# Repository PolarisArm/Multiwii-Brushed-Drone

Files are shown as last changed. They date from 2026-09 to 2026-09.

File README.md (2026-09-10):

# Multiwii-Brushed-Drone
Brushed Drone with Multiwii

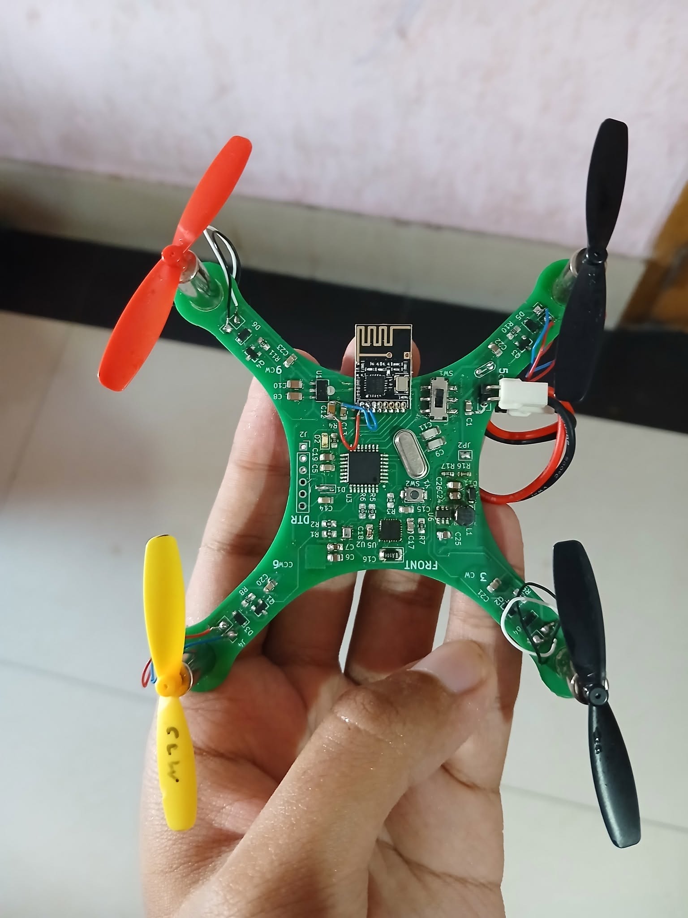
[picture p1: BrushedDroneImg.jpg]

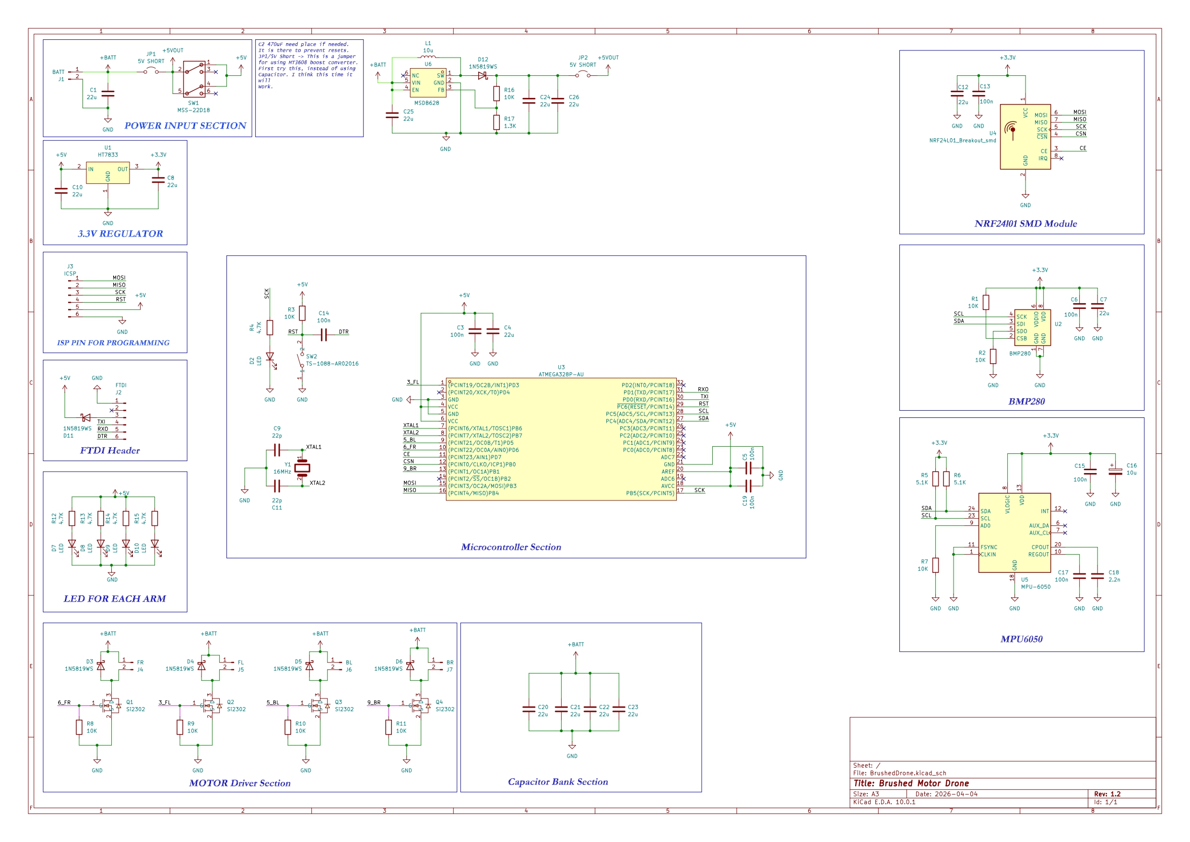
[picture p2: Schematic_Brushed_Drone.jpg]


# Orientation Code need to be changed as per MPU6050 Placement
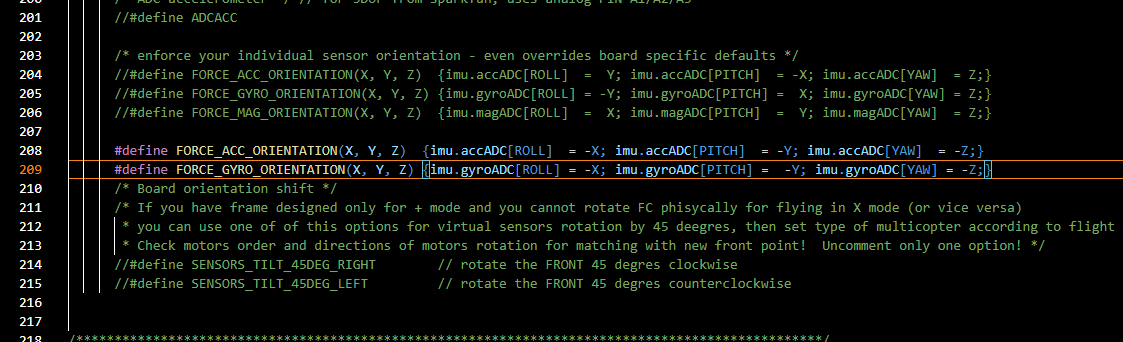
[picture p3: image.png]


# Vibration Issue mitigated by using low pass filter
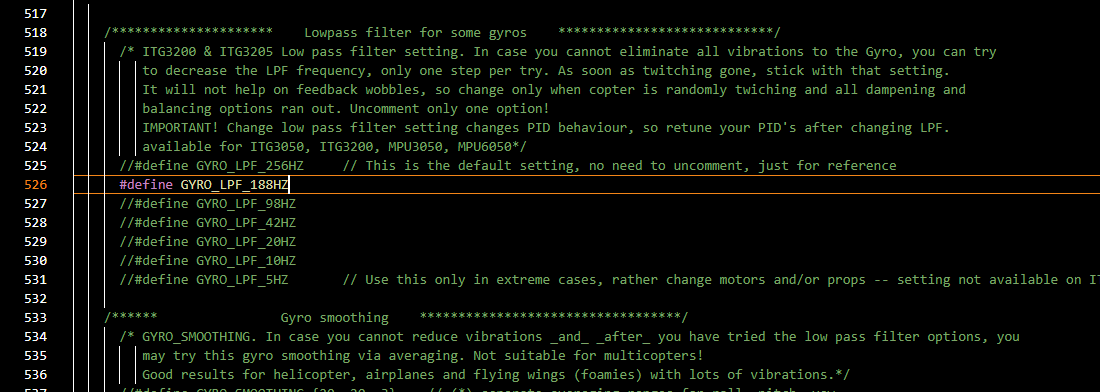
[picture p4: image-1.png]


# Dead band Added
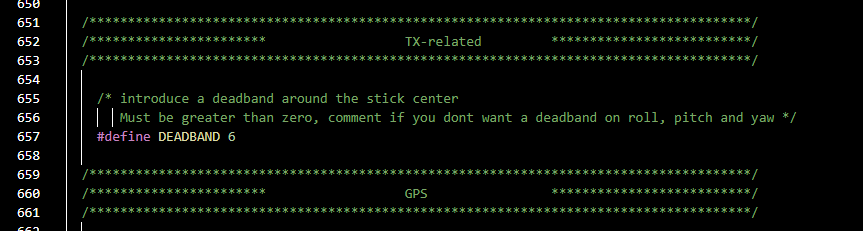
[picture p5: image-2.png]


# Multiwii 2.4 Software picture
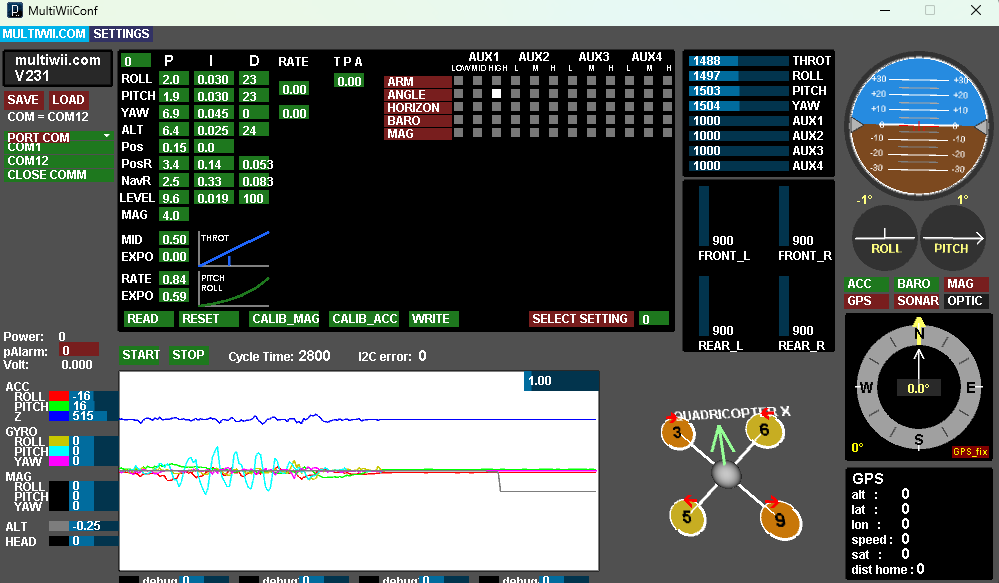
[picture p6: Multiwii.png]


#Transmitter Schematic
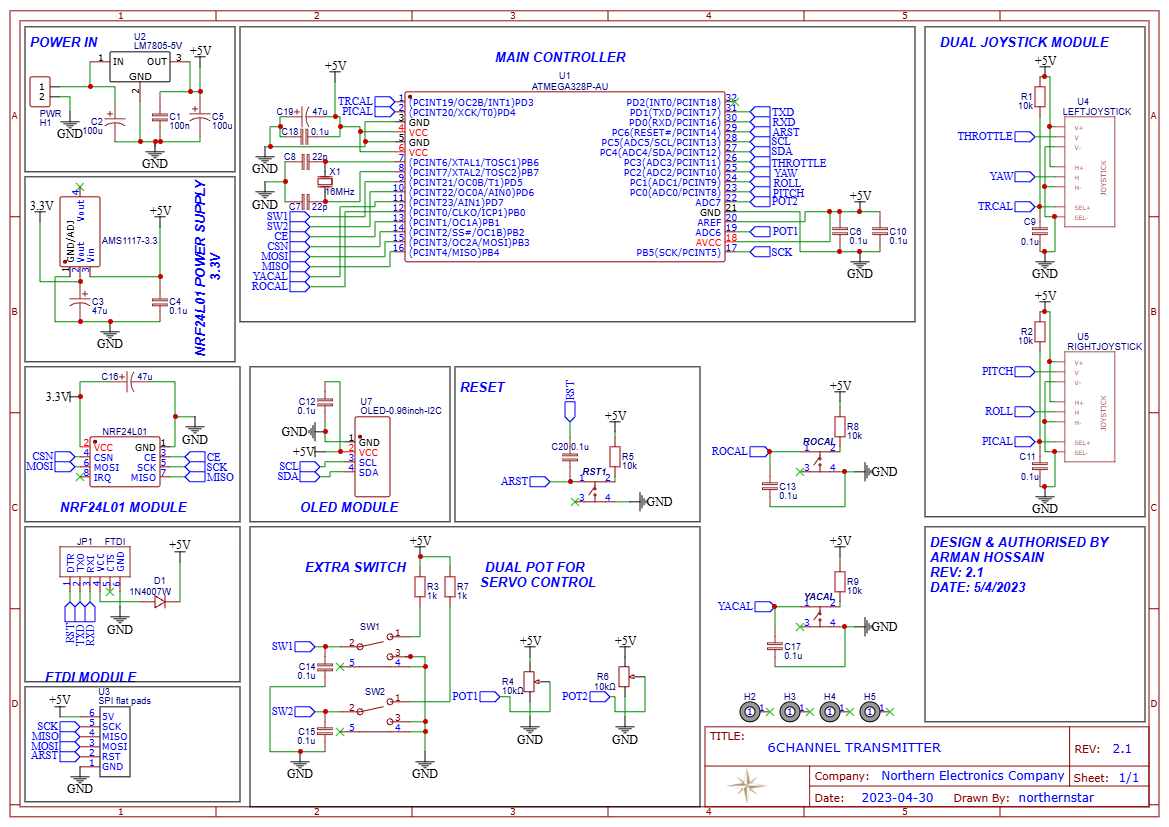
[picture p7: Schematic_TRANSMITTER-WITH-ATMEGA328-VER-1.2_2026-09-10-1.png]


# Transmitter
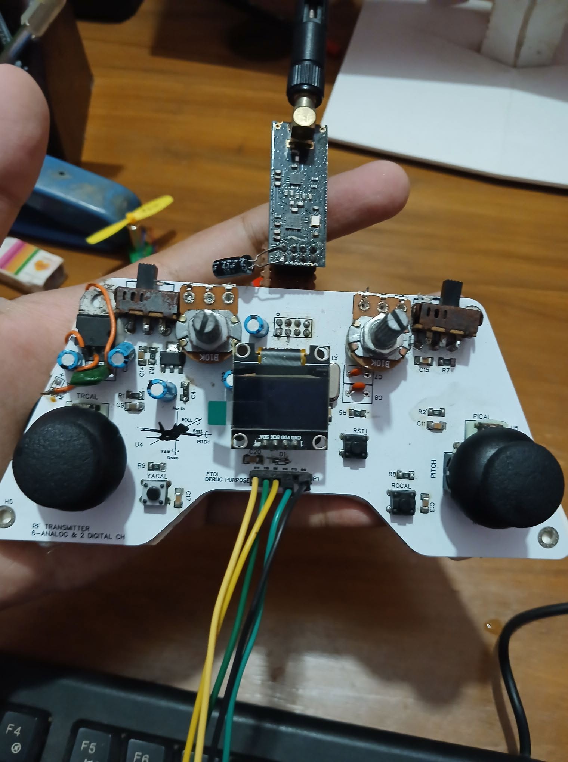
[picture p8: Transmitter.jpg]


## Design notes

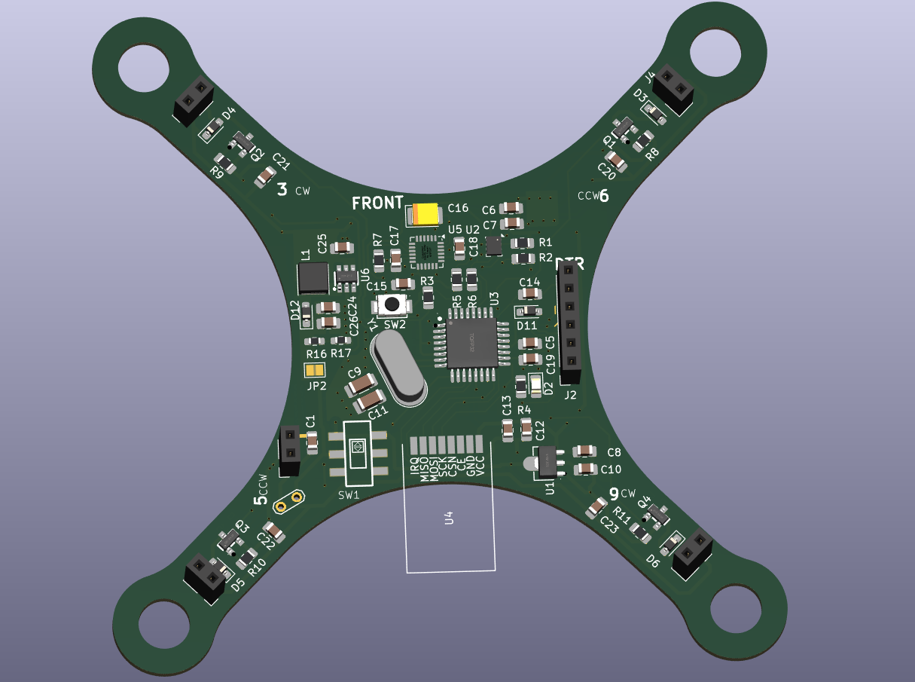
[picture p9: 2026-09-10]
PCB_3DView.png

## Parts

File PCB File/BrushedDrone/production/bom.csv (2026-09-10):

Designator | Footprint | Quantity | Value | LCSC Part #
C1, C10, C12, C20, C21, C22, C23, C24, C25, C26, C4, C7, C8 | 0805 | 13 | 22u
C11, C9 | 1206 | 2 | 22p
C13, C14, C15, C17, C19, C3, C5, C6 | 0805 | 8 | 100n
C16 | CP_EIA-3528-12_Kemet-T_HandSolder | 1 | 10u
C18 | 0805 | 1 | 2.2n
D1, D3, D4, D5, D6 | D_SOD-323_HandSoldering | 5 | 1N5819WS
D10, D2, D7, D8, D9 | 0805 | 5 | LED
D11 | D_SOD-323 | 1 | 1N5819WS
J1 | PinSocket_1x02_P2.54mm_Vertical | 1 | BATT
J2 | PinSocket_1x06_P2.54mm_Vertical | 1 | FTDI
J3 | ICSP_PAD | 1 | ICSP
J4 | PinSocket_1x02_P2.54mm_Vertical | 1 | FR
J5 | PinSocket_1x02_P2.54mm_Vertical | 1 | FL
J6 | PinSocket_1x02_P2.54mm_Vertical | 1 | BL
J7 | PinSocket_1x02_P2.54mm_Vertical | 1 | BR
JP1 | TestPoint_2Pads_Pitch2.54mm_Drill0.8mm | 1 | 5V SHORT
JP2 | SolderJumper-2_P1.3mm_Open_Pad1.0x1.5mm | 1 | 5V SHORT
L1 | L_APV_ANR4020 | 1 | 10u
Q1, Q2, Q3, Q4 | SOT-23_L2.9-W1.3-P1.90-LS2.4-BR | 4 | Si2302 | C10488
R1, R10, R11, R2, R3, R7, R8, R9 | 0805 | 8 | 10K
R12, R13, R14, R15, R4 | 0805 | 5 | 4.7K
R16 | 0603 | 1 | 10K
R17 | 0603 | 1 | 1.3K
R5, R6 | 0805 | 2 | 5.1K
SW1 | MSS2D18 | 1 | MSS-22D18
SW2 | SW-SMD_L3.9-W3.0-P4.45 | 1 | TS-1088-AR02016 | C720477
U1 | SOT-89_L4.5-W2.5-P1.50-LS4.2-BR | 1 | HT7833 | C50936
U2 | Bosch_LGA-8_2x2.5mm_P0.65mm_ClockwisePinNumbering | 1 | BMP280
U3 | TQFP-32_L7.0-W7.0-P0.80-LS9.0-BL | 1 | ATMEGA328P-AU | C14877
U4 | FootprintsKeyplus_nordic.prettyNRF24L01-Module-SMD | 1 | NRF24L01_Breakout_smd
U5 | InvenSense_QFN-24_4x4mm_P0.5mm | 1 | MPU-6050
U6 | SOT-23-6_L2.9-W1.6-P0.95-LS2.8-BR | 1 | MSDB628 | C30197563
Y1 | Crystal_HC49-4H_Vertical | 1 | 16MHz

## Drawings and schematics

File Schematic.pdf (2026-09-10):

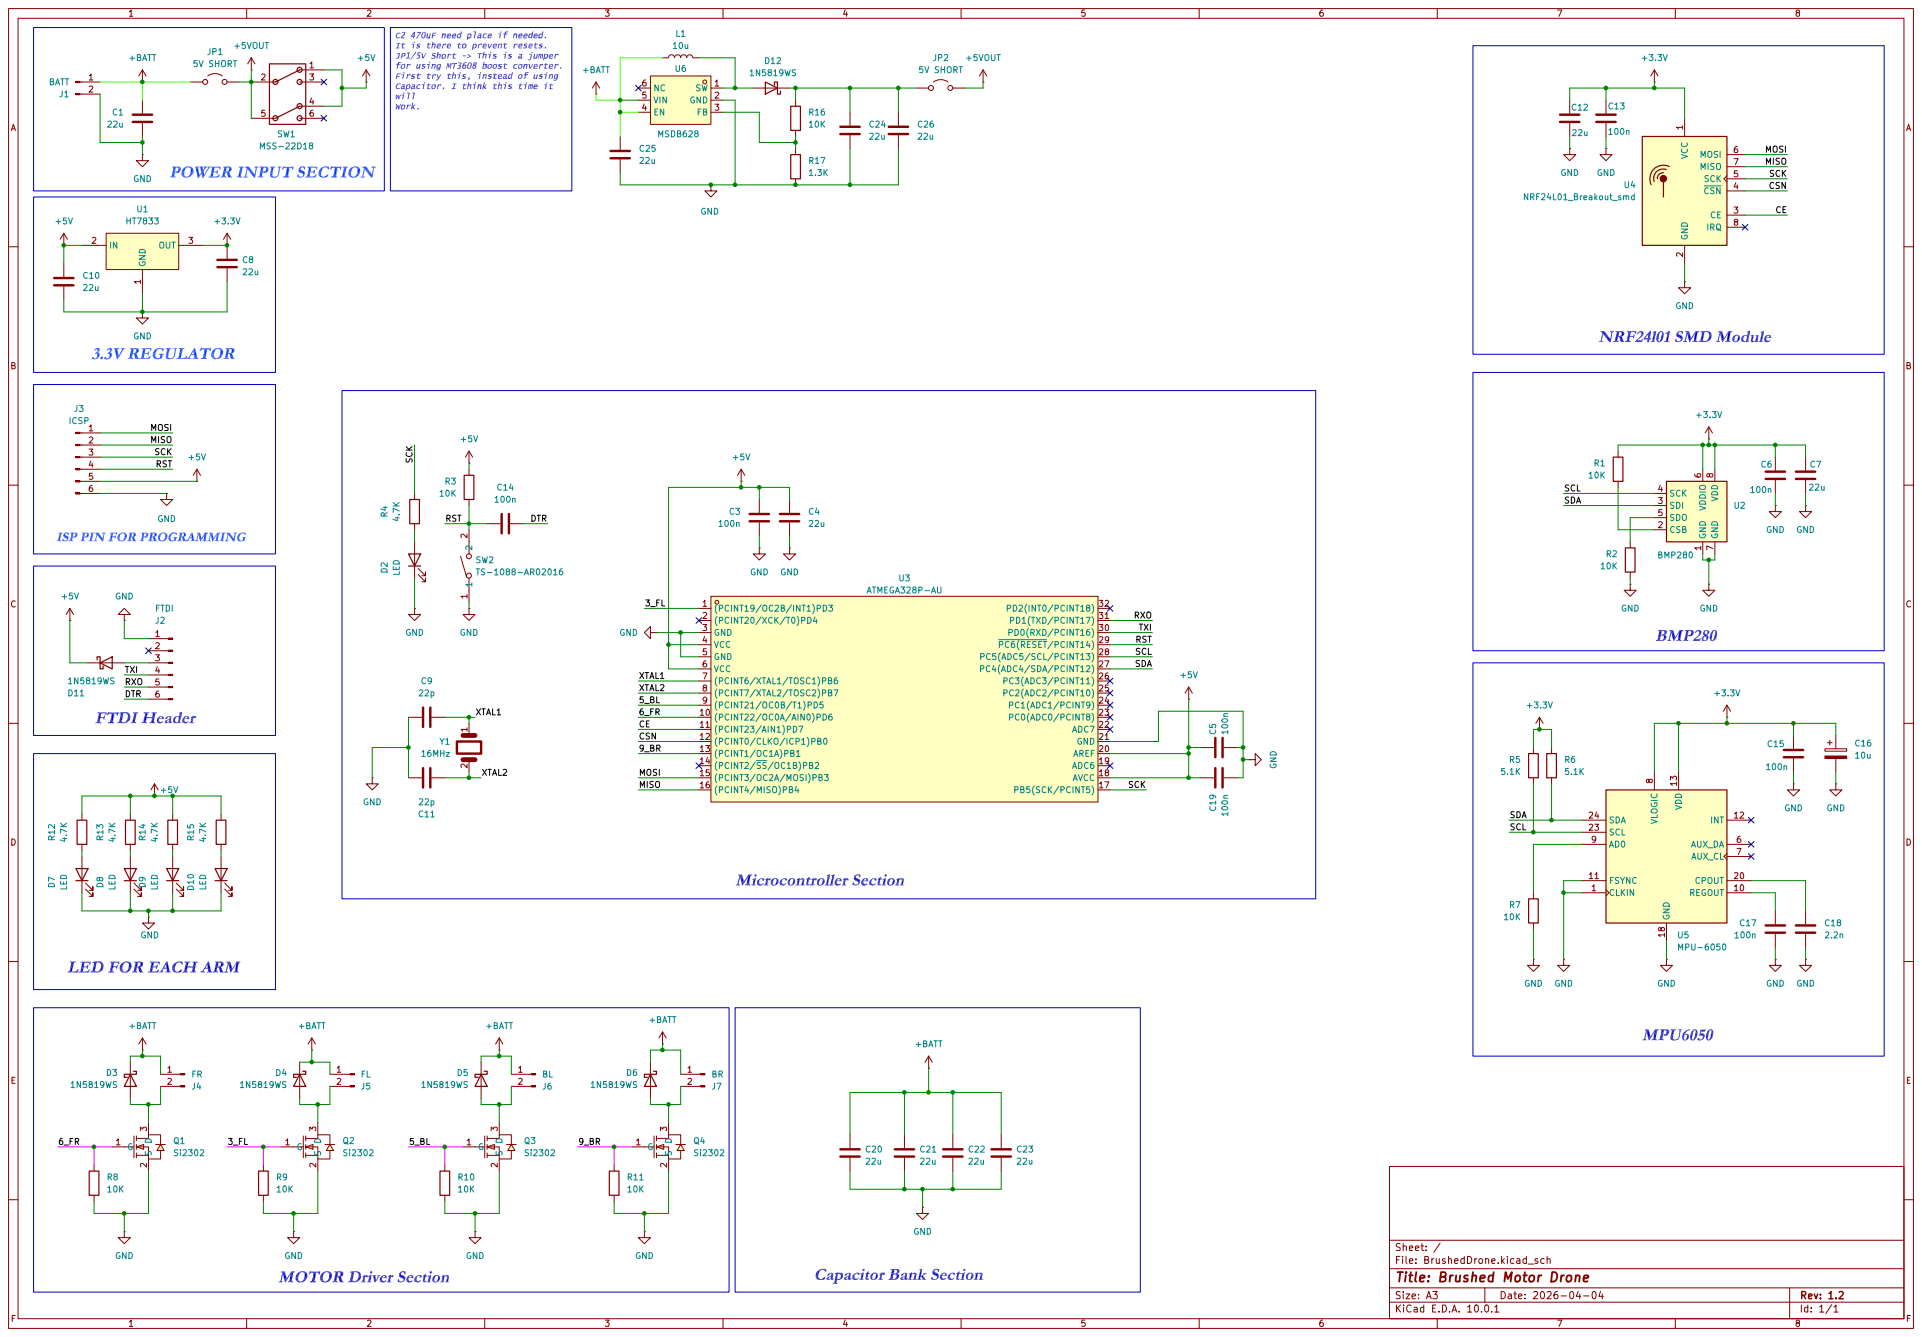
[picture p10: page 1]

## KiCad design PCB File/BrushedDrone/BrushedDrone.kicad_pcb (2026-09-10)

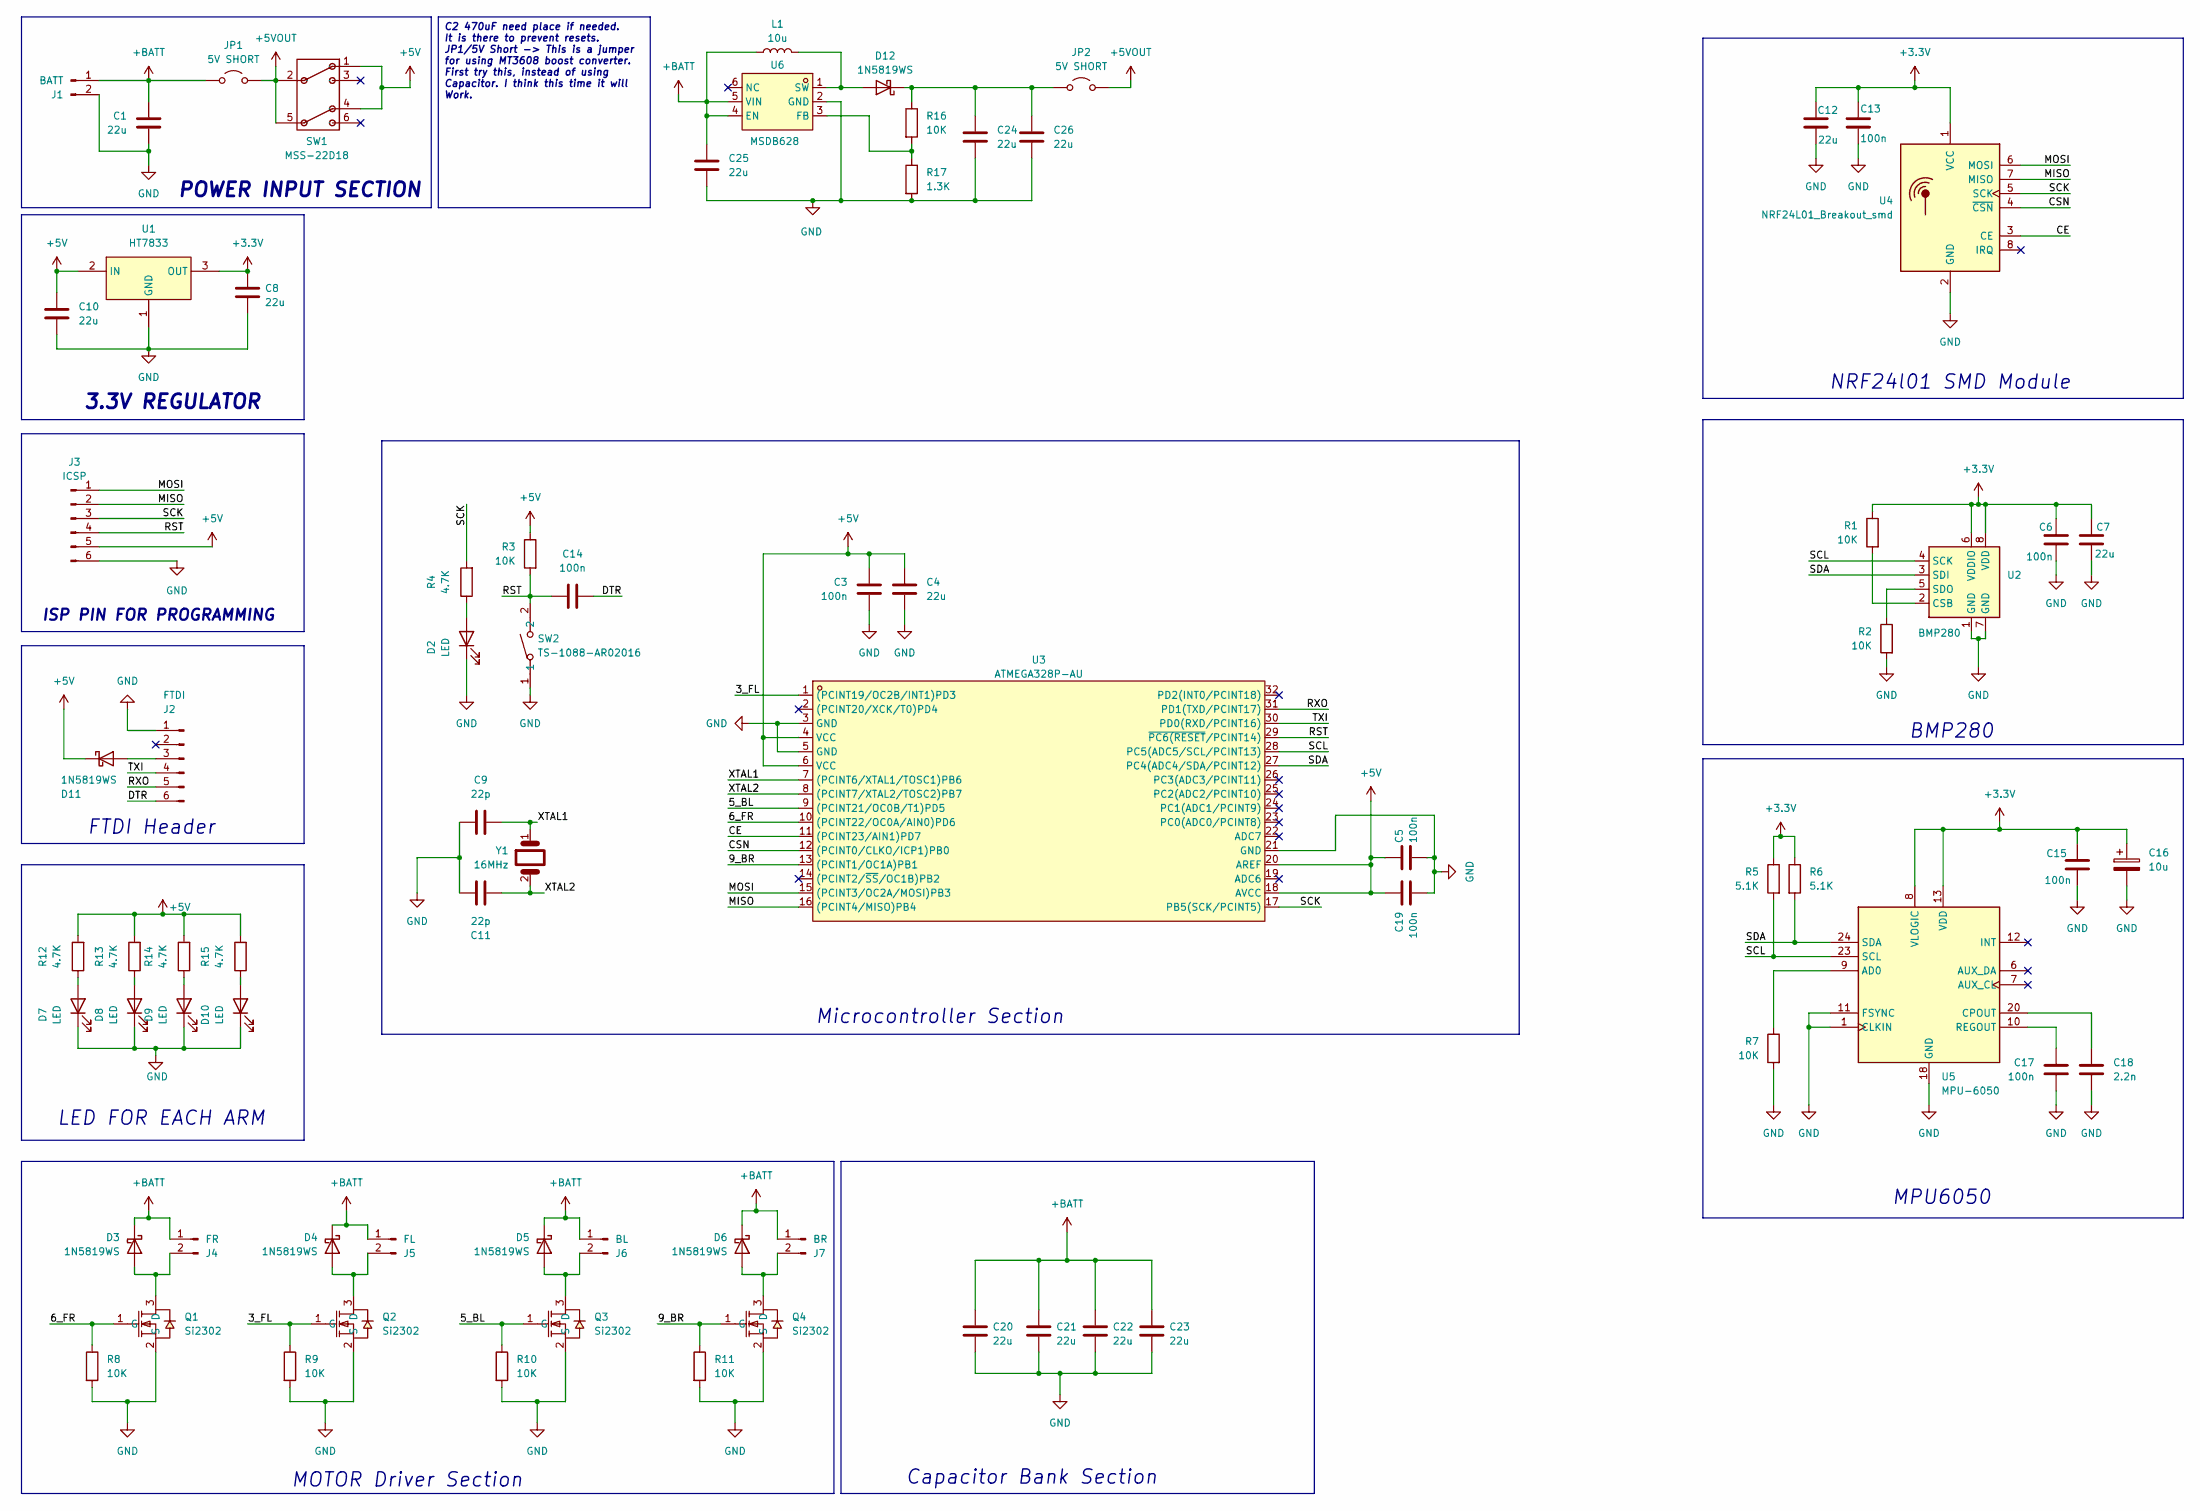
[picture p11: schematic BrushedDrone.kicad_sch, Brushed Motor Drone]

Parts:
C1, C4, C7, C8, C10, C12, C20, C21, C22, C23, C24, C25, C26: 22u; C_0805_2012Metric_Pad1.18x1.45mm_HandSolder
C3, C5, C6, C13, C14, C15, C17, C19: 100n; C_0805_2012Metric_Pad1.18x1.45mm_HandSolder
C9, C11: 22p; C_1206_3216Metric_Pad1.33x1.80mm_HandSolder
C16: 10u; CP_EIA-3528-12_Kemet-T_HandSolder
C18: 2.2n; C_0805_2012Metric_Pad1.18x1.45mm_HandSolder
D2, D7, D8, D9, D10: LED; LED_0805_2012Metric_Pad1.15x1.40mm_HandSolder
D3, D4, D5, D6, D11, D12: 1N5819WS; D_SOD-323_HandSoldering
J1: BATT; PinSocket_1x02_P2.54mm_Vertical
J2: FTDI; PinSocket_1x06_P2.54mm_Vertical
J3: ICSP; ICSP_PAD
J4: FR; PinSocket_1x02_P2.54mm_Vertical
J5: FL; PinSocket_1x02_P2.54mm_Vertical
J6: BL; PinSocket_1x02_P2.54mm_Vertical
J7: BR; PinSocket_1x02_P2.54mm_Vertical
JP1: 5V SHORT; TestPoint_2Pads_Pitch2.54mm_Drill0.8mm
JP2: 5V SHORT; SolderJumper-2_P1.3mm_Open_Pad1.0x1.5mm
L1: 10u; L_APV_ANR4020
Q1, Q2, Q3, Q4: Si2302; SOT-23_L2.9-W1.3-P1.90-LS2.4-BR; MPN Si2302CDS-T1-GE3; LCSC Part C10488
R1, R2, R3, R7, R8, R9, R10, R11: 10K; R_0805_2012Metric_Pad1.20x1.40mm_HandSolder
R4, R12, R13, R14, R15: 4.7K; R_0805_2012Metric_Pad1.20x1.40mm_HandSolder
R5, R6: 5.1K; R_0805_2012Metric_Pad1.20x1.40mm_HandSolder
R16: 10K; R_0603_1608Metric_Pad0.98x0.95mm_HandSolder
R17: 1.3K; R_0603_1608Metric_Pad0.98x0.95mm_HandSolder
SW1: MSS-22D18; MSS2D18
SW2: TS-1088-AR02016; SW-SMD_L3.9-W3.0-P4.45; MPN TS-1088-AR02016; LCSC Part C720477
U1: HT7833; SOT-89_L4.5-W2.5-P1.50-LS4.2-BR; MPN HT7833; LCSC Part C50936
U2: BMP280; Bosch_LGA-8_2x2.5mm_P0.65mm_ClockwisePinNumbering
U3: ATMEGA328P-AU; TQFP-32_L7.0-W7.0-P0.80-LS9.0-BL; MPN ATMEGA328P-AU; LCSC Part C14877
U4: NRF24L01_Breakout_smd; FootprintsKeyplus_nordic.prettyNRF24L01-Module-SMD
U5: MPU-6050; InvenSense_QFN-24_4x4mm_P0.5mm
U6: MSDB628; SOT-23-6_L2.9-W1.6-P0.95-LS2.8-BR; MPN MSDB628; LCSC Part C30197563
Y1: 16MHz; Crystal_HC49-4H_Vertical

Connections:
+3.3V: C6.1, C7.1, C8.1, C12.1, C13.1, C15.1, C16.1, R1.1, R5.1, R6.1, U1.3 (OUT), U2.6 (VDDIO), U2.8 (VDD), U4.1 (VCC), U5.8 (VLOGIC), U5.13 (VDD)
+5V: C3.1, C4.1, C5.1, C10.1, C19.1, D11.1 (K), J3.5, R3.1, R12.2, R13.2, R14.2, R15.2, SW1.1, SW1.4, U1.2 (IN), U3.4 (VCC), U3.6 (VCC), U3.18 (AVCC), U3.20 (AREF)
+5VOUT: JP1.2 (B), JP2.2 (B), SW1.2, SW1.5
+BATT: C1.1, C20.1, C21.1, C22.1, C23.1, C25.1, D3.1 (K), D4.1 (K), D5.1 (K), D6.1 (K), J1.1, J4.1, J5.1, J6.1, J7.1, JP1.1 (A), L1.1, U6.4 (EN), U6.5 (VIN)
/3_FL: Q2.1 (G), R9.1, U3.1 ((PCINT19/OC2B/INT1)PD3)
/5_BL: Q3.1 (G), R10.1, U3.9 ((PCINT21/OC0B/T1)PD5)
/6_FR: Q1.1 (G), R8.1, U3.10 ((PCINT22/OC0A/AIN0)PD6)
/9_BR: Q4.1 (G), R11.1, U3.13 ((PCINT1/OC1A)PB1)
/CE: U3.11 ((PCINT23/AIN1)PD7), U4.3 (CE)
/CSN: U3.12 ((PCINT0/CLKO/ICP1)PB0), U4.4 (~CSN)
/DTR: C14.2, J2.6
/MISO: J3.2, U3.16 ((PCINT4/MISO)PB4), U4.7 (MISO)
/MOSI: J3.1, U3.15 ((PCINT3/OC2A/MOSI)PB3), U4.6 (MOSI)
/RST: C14.1, J3.4, R3.2, SW2.2, U3.29 (~PC6(RESET/PCINT14))
/RXO: J2.5, U3.31 (PD1(TXD/PCINT17))
/SCK: J3.3, R4.2, U3.17 (PB5(SCK/PCINT5)), U4.5 (SCK)
/SCL: R5.2, U2.4 (SCK), U3.28 (PC5(ADC5/SCL/PCINT13)), U5.23 (SCL)
/SDA: R6.2, U2.3 (SDI), U3.27 (PC4(ADC4/SDA/PCINT12)), U5.24 (SDA)
/TXI: J2.4, U3.30 (PD0(RXD/PCINT16))
/XTAL1: C9.1, U3.7 ((PCINT6/XTAL1/TOSC1)PB6), Y1.1
/XTAL2: C11.1, U3.8 ((PCINT7/XTAL2/TOSC2)PB7), Y1.2
GND: C1.2, C3.2, C4.2, C5.2, C6.2, C7.2, C8.2, C9.2, C10.2, C11.2, C12.2, C13.2, C15.2, C16.2, C17.2, C18.2, C19.2, C20.2, C21.2, C22.2, C23.2, C24.2, C25.2, C26.2, D2.1 (K), D7.1 (K), D8.1 (K), D9.1 (K), D10.1 (K), J1.2, J2.1, J3.6, Q1.2 (S), Q2.2 (S), Q3.2 (S), Q4.2 (S), R2.2, R7.2, R8.2, R9.2, R10.2, R11.2, R17.2, SW2.1, U1.1 (GND), U2.1 (GND), U2.7 (GND), U3.3 (GND), U3.5 (GND), U3.21 (GND), U4.2 (GND), U5.1 (CLKIN), U5.11 (FSYNC), U5.18 (GND), U6.2 (GND)
unnamed: D2.2 (A), R4.1
unnamed: D3.2 (A), J4.2, Q1.3 (D)
unnamed: D4.2 (A), J5.2, Q2.3 (D)
unnamed: D5.2 (A), J6.2, Q3.3 (D)
unnamed: D6.2 (A), J7.2, Q4.3 (D)
unnamed: D7.2 (A), R12.1
unnamed: D8.2 (A), R13.1
unnamed: D9.2 (A), R14.1
unnamed: D10.2 (A), R15.1
unnamed: D11.2 (A), J2.3
unnamed: D12.2 (A), L1.2, U6.1 (SW)
unnamed: C24.1, C26.1, D12.1 (K), JP2.1 (A), R16.1
unnamed: R1.2, U2.2 (CSB)
unnamed: R2.1, U2.5 (SDO)
unnamed: R7.1, U5.9 (AD0)
unnamed: C18.1, U5.20 (CPOUT)
unnamed: C17.1, U5.10 (REGOUT)
unnamed: R16.2, R17.1, U6.3 (FB)

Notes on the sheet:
NRF24l01 SMD Module
BMP280
ISP PIN FOR PROGRAMMING
MOTOR Driver Section
MPU6050
LED FOR EACH ARM
POWER INPUT SECTION
Microcontroller Section
3.3V REGULATOR
Capacitor Bank Section
FTDI Header
C2 470uF need place if needed. It is there to prevent resets. JP1/5V Short -> This is a jumper for using MT3608 boost converter. First try this, instead of using Capacitor. I think this time it will Work.

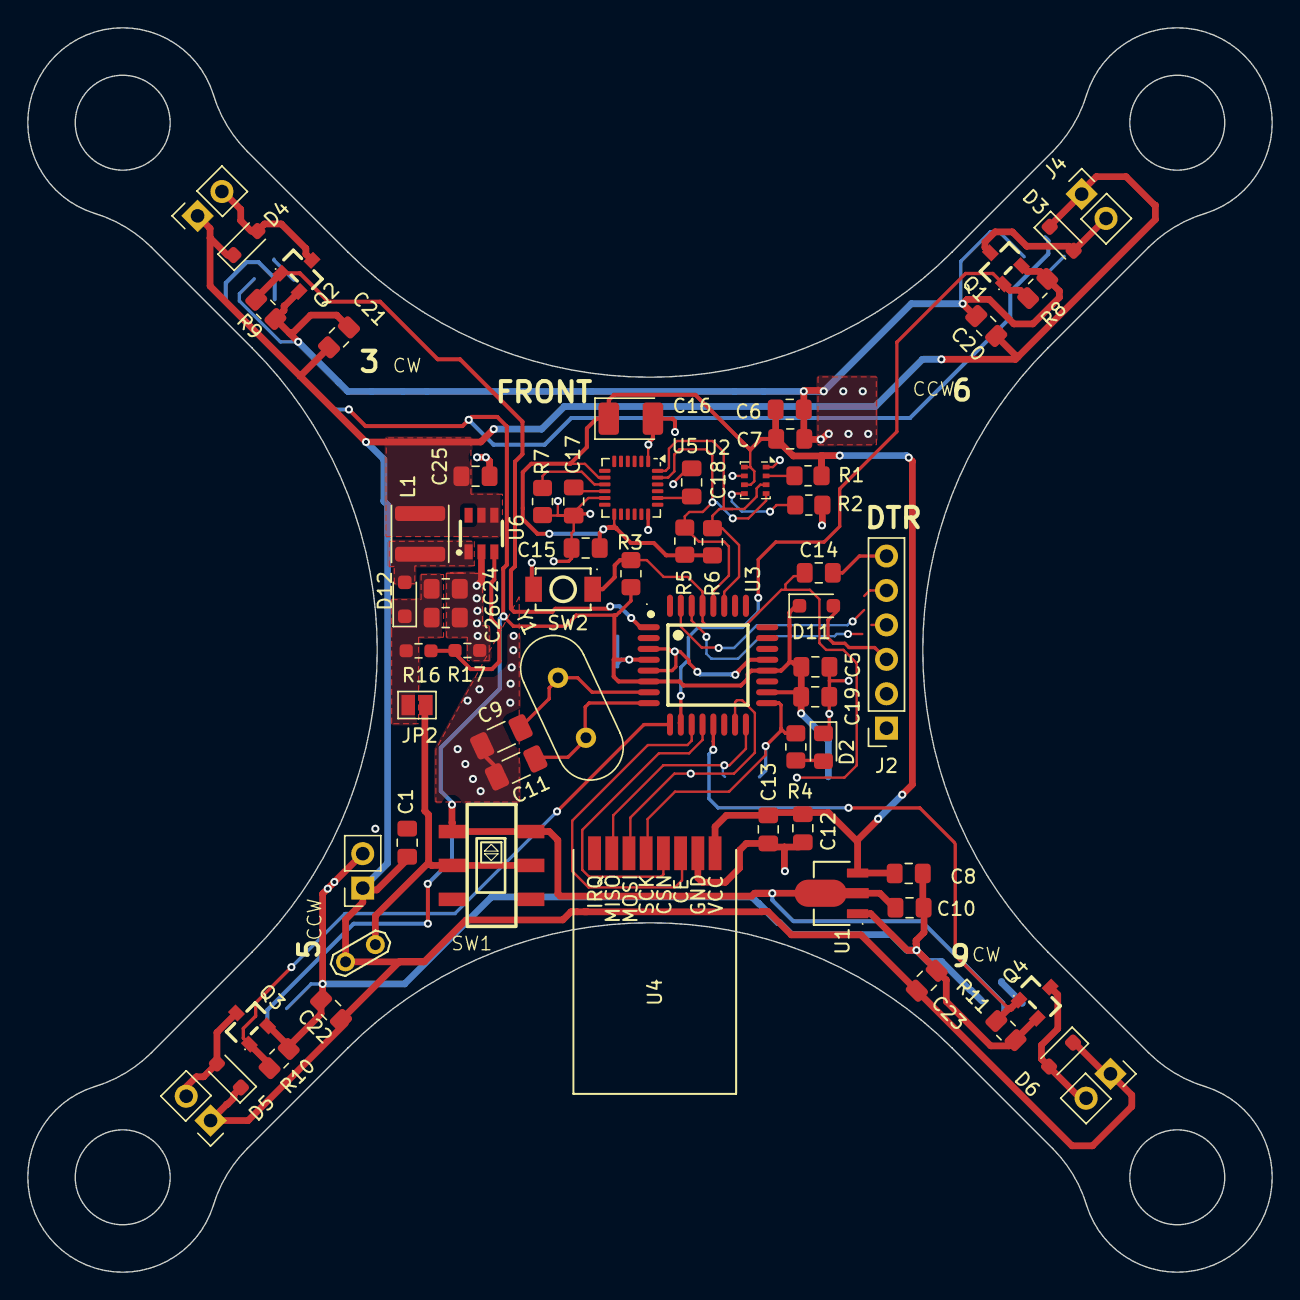
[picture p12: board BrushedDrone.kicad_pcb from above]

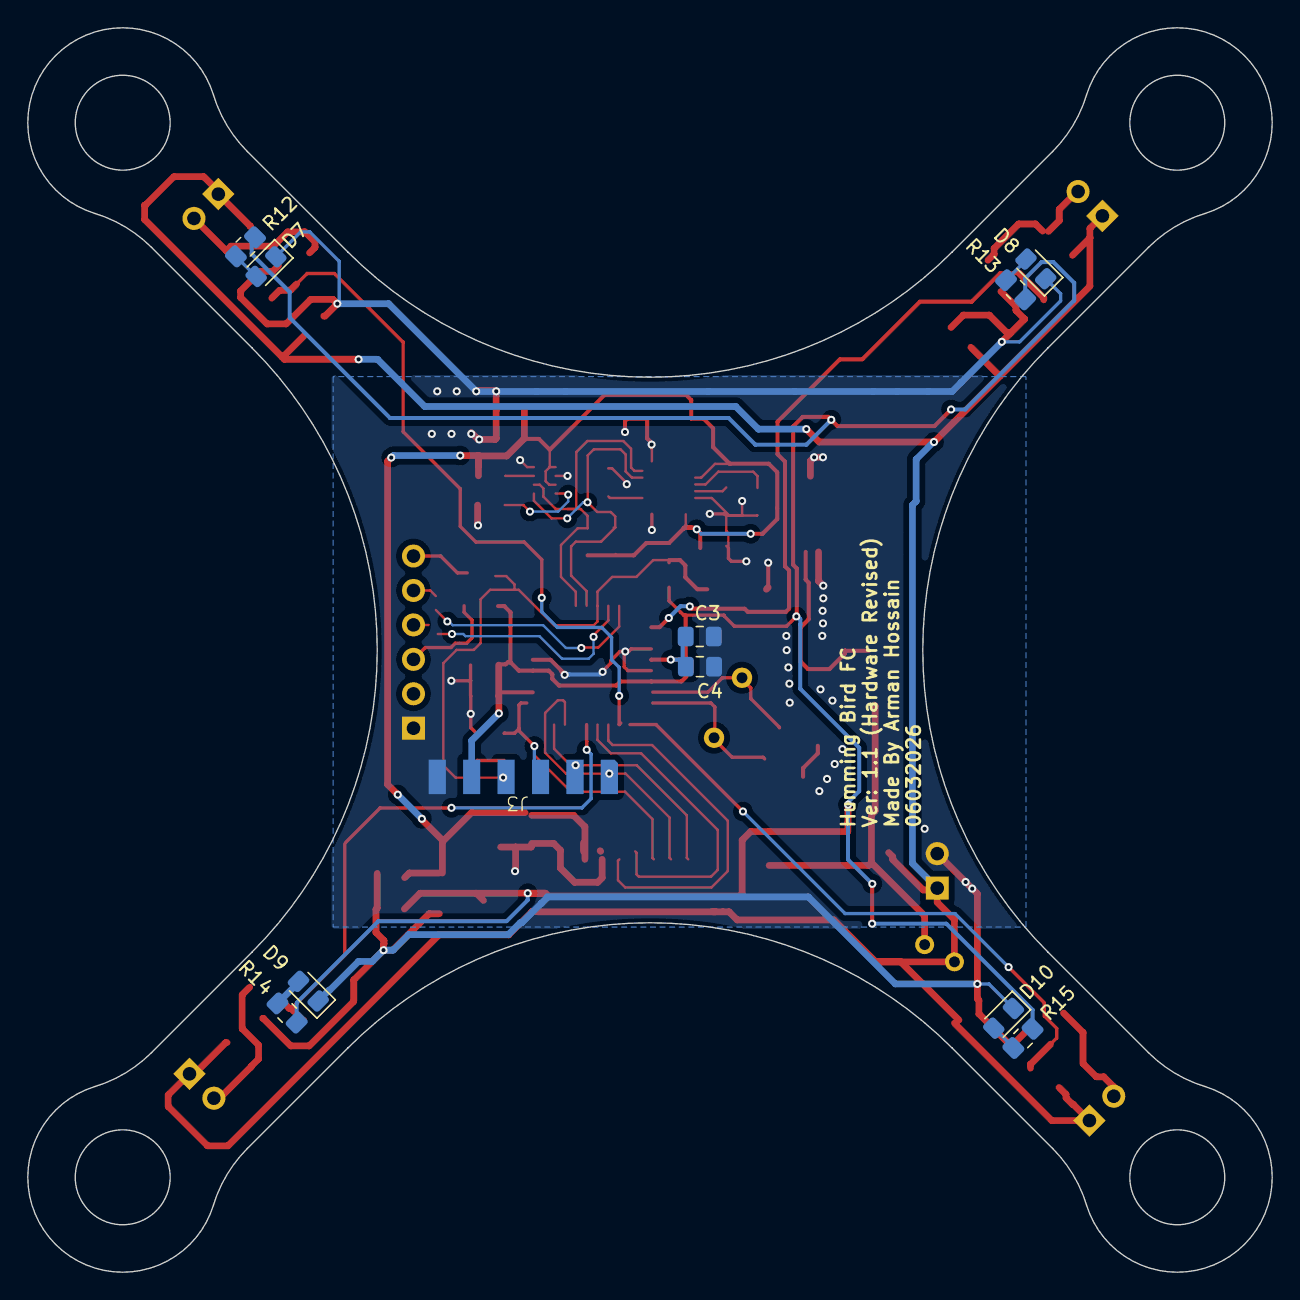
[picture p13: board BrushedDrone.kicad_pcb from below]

Board: 2 copper layers, 91.8 x 91.8 mm, 76 parts (11 on the bottom side), 40 nets.

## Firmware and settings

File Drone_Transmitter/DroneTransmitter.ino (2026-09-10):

#include <Arduino.h>
#include <Adafruit_GFX.h>
#include <Adafruit_SSD1306.h>
#include <RF24.h>

#define CE         9
#define CSN       10
#define ROLL      A1
#define PITCH     A0
#define YAW       A2
#define THROTTLE  A3
#define SW1        5
#define SW2        6
#define POT1      A6
#define POT2      A7
#define TRCAL      3
#define YACAL      7
#define PICAL      4
#define ROCAL      8


#define SCREEN_WIDTH 128 // OLED display width, in pixels
#define SCREEN_HEIGHT 64 // OLED display height, in pixels

#define OLED_RESET     -1 // Reset pin # (or -1 if sharing Arduino reset pin)
#define SCREEN_ADDRESS 0x3C /// 0x3C for 128x64
Adafruit_SSD1306 display(SCREEN_WIDTH, SCREEN_HEIGHT);

int PITCH_CENTER = 0, ROLL_CENTER = 0, YAW_CENTER = 0, THROTTLE_CENTER = 0;

const unsigned char WELCOME_SCREEN [] PROGMEM = {
	0xff, 0xff, 0xff, 0xff, 0xff, 0xff, 0xff, 0xff, 0xff, 0xff, 0xff, 0xff, 0xff, 0xff, 0xff, 0xff, 
	0xff, 0xff, 0xff, 0xff, 0xff, 0xff, 0xff, 0xff, 0xff, 0xff, 0xff, 0xff, 0xff, 0xff, 0xff, 0xff, 
	0xff, 0xff, 0xff, 0xff, 0xff, 0xff, 0xff, 0xff, 0xff, 0xff, 0xff, 0xff, 0xff, 0xff, 0xff, 0xff, 
	0xff, 0xff, 0xff, 0xff, 0xff, 0xff, 0xff, 0xff, 0xff, 0xff, 0xff, 0xff, 0xff, 0xff, 0xff, 0xff, 
	0xff, 0xff, 0xff, 0xff, 0xff, 0xff, 0xff, 0xff, 0xff, 0xff, 0xff, 0xff, 0xff, 0xff, 0xff, 0xff, 
	0xff, 0xff, 0xff, 0xff, 0xff, 0xff, 0xff, 0xff, 0xff, 0xff, 0xff, 0xff, 0xff, 0xff, 0xff, 0xff, 
	0xff, 0xff, 0xff, 0xff, 0xff, 0xff, 0xff, 0xff, 0xff, 0xff, 0xff, 0xff, 0xff, 0xff, 0xff, 0xff, 
	0xc0, 0x07, 0xe0, 0x18, 0x1f, 0xf8, 0x0e, 0x00, 0x38, 0x1f, 0x00, 0x7f, 0xfc, 0x00, 0x7c, 0x01, 
	0xd0, 0x03, 0x40, 0x0a, 0x1f, 0xd0, 0x06, 0x80, 0x1a, 0x1a, 0x00, 0x7f, 0xfd, 0x00, 0x28, 0x03, 
	0xc0, 0xc3, 0x03, 0x08, 0x1f, 0xc0, 0xc2, 0x06, 0x18, 0x18, 0x00, 0xff, 0xfc, 0x0c, 0x20, 0x7f, 
	0xc0, 0xc3, 0x03, 0x08, 0x1f, 0xc0, 0xc2, 0x06, 0x18, 0x18, 0x1f, 0xff, 0xfc, 0x0c, 0x20, 0x7f, 
	0xc0, 0xc3, 0x03, 0x08, 0x1f, 0xc0, 0x02, 0x00, 0x38, 0x18, 0x00, 0xff, 0xfc, 0x00, 0x60, 0x7f, 
	0xc0, 0x03, 0x03, 0x08, 0x1f, 0xc0, 0xc2, 0x00, 0x78, 0x1c, 0x00, 0x7f, 0xfc, 0x00, 0xe0, 0x7f, 
	0xc0, 0x07, 0x03, 0x08, 0x1f, 0xc0, 0xc2, 0x00, 0x38, 0x1f, 0xf8, 0x7f, 0xfc, 0x00, 0x60, 0x7f, 
	0xc0, 0x0f, 0x03, 0x08, 0x1f, 0xc0, 0xc2, 0x00, 0x18, 0x1c, 0x00, 0x7f, 0xfc, 0x00, 0x20, 0x7f, 
	0xc0, 0xff, 0x00, 0x08, 0x01, 0xc0, 0xc2, 0x04, 0x18, 0x18, 0x00, 0x7f, 0xfc, 0x08, 0x20, 0x03, 
	0xc0, 0xff, 0x80, 0x18, 0x00, 0xc0, 0xc2, 0x06, 0x18, 0x18, 0x00, 0xff, 0xfc, 0x0c, 0x30, 0x01, 
	0xe1, 0xff, 0xc0, 0x3c, 0x01, 0xe1, 0xe7, 0x0f, 0x3c, 0x3c, 0x01, 0xff, 0xfe, 0x1e, 0x78, 0x03, 
	0xff, 0xff, 0xff, 0xff, 0xff, 0xff, 0xff, 0xff, 0xff, 0xff, 0xff, 0xff, 0xff, 0xff, 0xff, 0xff, 
	0xff, 0xff, 0xff, 0xff, 0xff, 0xff, 0xff, 0xff, 0xff, 0xff, 0xff, 0xff, 0xff, 0xff, 0xff, 0xff, 
	0xff, 0xff, 0xff, 0xff, 0xff, 0xff, 0xff, 0xff, 0xff, 0xff, 0xff, 0xff, 0xff, 0xff, 0xff, 0xff, 
	0xff, 0xff, 0xff, 0xff, 0xff, 0xff, 0xff, 0xff, 0xff, 0xff, 0xff, 0xff, 0xff, 0xff, 0xff, 0xff, 
	0xff, 0xff, 0xff, 0xff, 0xff, 0xc7, 0x8f, 0xff, 0xff, 0xff, 0xff, 0xff, 0xff, 0xff, 0xff, 0xff, 
	0xff, 0xff, 0x80, 0x20, 0x03, 0xb3, 0x07, 0xff, 0xff, 0xff, 0xff, 0x00, 0x78, 0x0f, 0x00, 0x1f, 
	0xff, 0xfd, 0x00, 0x28, 0x01, 0xa0, 0x07, 0xff, 0xff, 0xff, 0xfa, 0x00, 0xd0, 0x07, 0x40, 0x0f, 
	0xff, 0xfc, 0x00, 0x60, 0x61, 0xc0, 0x0f, 0xff, 0xff, 0xff, 0xf8, 0x1f, 0xc0, 0xc3, 0x03, 0x0f, 
	0xff, 0xfc, 0x0f, 0xe0, 0x61, 0xc0, 0x0f, 0xff, 0xff, 0xff, 0xf8, 0x1f, 0xc0, 0xc3, 0x03, 0x0f, 
	0xff, 0xfc, 0x00, 0x60, 0x61, 0xe0, 0x1f, 0xff, 0xff, 0xff, 0xf8, 0x1f, 0xc0, 0x03, 0x00, 0x1f, 
	0xff, 0xfe, 0x00, 0x20, 0x01, 0xf0, 0x7f, 0xff, 0xff, 0xff, 0xf8, 0x1f, 0xc0, 0xc3, 0x00, 0x3f, 
	0xff, 0xff, 0xfc, 0x20, 0x03, 0xf0, 0x7f, 0xff, 0xff, 0xff, 0xf8, 0x1f, 0xc0, 0xc3, 0x00, 0x1f, 
	0xff, 0xfe, 0x00, 0x20, 0x07, 0xf0, 0x7f, 0xff, 0xff, 0xff, 0xf8, 0x1f, 0xc0, 0xc3, 0x00, 0x0f, 
	0xff, 0xfc, 0x00, 0x20, 0x7f, 0xf0, 0x7f, 0xff, 0xff, 0xff, 0xf8, 0x00, 0xc0, 0xc3, 0x02, 0x0f, 
	0xff, 0xfc, 0x00, 0x60, 0x7f, 0xf0, 0x7f, 0xff, 0xff, 0xff, 0xfc, 0x00, 0x40, 0xc3, 0x03, 0x0f, 
	0xff, 0xfe, 0x00, 0xf0, 0xff, 0xf8, 0x7f, 0xff, 0xff, 0xff, 0xfe, 0x00, 0xe1, 0xe7, 0x87, 0x9f, 
	0xff, 0xff, 0xff, 0xff, 0xff, 0xff, 0xff, 0xff, 0xff, 0xff, 0xff, 0xff, 0xff, 0xff, 0xff, 0xff, 
	0x00, 0x00, 0x00, 0x00, 0x00, 0x00, 0x00, 0x00, 0x00, 0x00, 0x00, 0x00, 0x00, 0x00, 0x00, 0x00, 
	0x00, 0x00, 0x00, 0x00, 0x00, 0x00, 0x00, 0x00, 0x00, 0x00, 0x00, 0x00, 0x00, 0x00, 0x00, 0x00, 
	0x00, 0x00, 0x00, 0x00, 0x00, 0x00, 0x00, 0x00, 0x00, 0x00, 0x00, 0x00, 0x00, 0x00, 0x00, 0x00, 
	0xff, 0xff, 0xff, 0xff, 0xff, 0xff, 0xff, 0xff, 0xff, 0xff, 0xff, 0xff, 0xff, 0xff, 0xff, 0xff, 
	0xff, 0xff, 0x81, 0xf3, 0xc0, 0x00, 0x60, 0x00, 0x7f, 0xfc, 0x03, 0xff, 0xc0, 0x07, 0xff, 0xff, 
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
};


const unsigned char HOME [] PROGMEM = {
	0x00, 0x00, 0x00, 0x00, 0x00, 0x00, 0x00, 0x00, 0x00, 0x00, 0x00, 0x00, 0x00, 0x00, 0x00, 0x00, 
	0xff, 0xff, 0xff, 0xff, 0xff, 0xff, 0xff, 0xff, 0xff, 0xff, 0xff, 0xff, 0xff, 0xff, 0xff, 0xfc, 
	0x80, 0x00, 0x00, 0x00, 0x00, 0x00, 0x00, 0x00, 0x00, 0x00, 0x38, 0x00, 0x00, 0x00, 0x00, 0x04, 
	0x80, 0x00, 0x00, 0x00, 0x00, 0x00, 0x00, 0x00, 0x00, 0x00, 0x38, 0x00, 0x00, 0x00, 0x00, 0x04, 
	0x9c, 0x88, 0xe0, 0x00, 0x00, 0x00, 0x00, 0x00, 0x00, 0x00, 0x38, 0x00, 0x00, 0x00, 0x00, 0x04, 
	0xa2, 0x89, 0x10, 0x00, 0x00, 0x00, 0x00, 0x00, 0x00, 0x00, 0x38, 0x08, 0xf1, 0xb1, 0x8c, 0x84, 
	0xa0, 0xf9, 0x30, 0x00, 0x00, 0x00, 0x00, 0x00, 0x00, 0x00, 0x38, 0x14, 0xc9, 0x52, 0xca, 0x84, 
	0xa0, 0x89, 0x50, 0x00, 0x00, 0x00, 0x00, 0x00, 0x00, 0x00, 0x38, 0x22, 0xc9, 0x54, 0x69, 0x84, 
	0xa0, 0x89, 0x90, 0x00, 0x00, 0x00, 0x00, 0x00, 0x00, 0x00, 0x38, 0x3e, 0xf1, 0x17, 0xe8, 0x84, 
	0xa2, 0x89, 0x10, 0x00, 0x00, 0x00, 0x00, 0x00, 0x00, 0x00, 0x38, 0x22, 0xc9, 0x14, 0x68, 0x84, 
	0x9c, 0x88, 0xe0, 0x00, 0x00, 0x00, 0x00, 0x00, 0x00, 0x00, 0x38, 0x22, 0xc5, 0x14, 0x68, 0x84, 
	0x80, 0x00, 0x00, 0x00, 0x00, 0x00, 0x00, 0x00, 0x00, 0x00, 0x38, 0x00, 0x00, 0x00, 0x00, 0x04, 
	0x80, 0x00, 0x00, 0x00, 0x00, 0x00, 0x00, 0x00, 0x00, 0x00, 0x38, 0x00, 0x00, 0x00, 0x00, 0x04, 
	0x9c, 0x88, 0x40, 0x00, 0x00, 0x00, 0x00, 0x00, 0x00, 0x00, 0x3f, 0xff, 0xff, 0xff, 0xff, 0xfc, 
	0xa2, 0x88, 0xc0, 0x00, 0x00, 0x00, 0x00, 0x00, 0x00, 0x00, 0x3f, 0xff, 0xff, 0xff, 0xff, 0xfc, 
	0xa0, 0xf8, 0x40, 0x00, 0x00, 0x00, 0x00, 0x00, 0x00, 0x00, 0x3f, 0xff, 0xff, 0xff, 0xff, 0xfc, 
	0xa0, 0x88, 0x40, 0x00, 0x00, 0x00, 0x00, 0x00, 0x00, 0x00, 0x38, 0x00, 0x01, 0xc0, 0x00, 0x04, 
	0xa0, 0x88, 0x40, 0x00, 0x00, 0x00, 0x00, 0x00, 0x00, 0x00, 0x38, 0x00, 0x01, 0xc0, 0x00, 0x04, 
	0xa2, 0x88, 0x40, 0x00, 0x00, 0x00, 0x00, 0x00, 0x00, 0x00, 0x3b, 0xf3, 0x0d, 0xdf, 0x98, 0x64, 
	0x9c, 0x89, 0xf0, 0x00, 0x00, 0x00, 0x00, 0x00, 0x00, 0x00, 0x3b, 0xf3, 0x0d, 0xdf, 0x98, 0x64, 
	0x80, 0x00, 0x00, 0x00, 0x00, 0x00, 0x00, 0x00, 0x00, 0x00, 0x3b, 0x03, 0x0d, 0xd8, 0x18, 0x64, 
	0x80, 0x00, 0x00, 0x00, 0x00, 0x00, 0x00, 0x00, 0x00, 0x00, 0x3b, 0xf3, 0x6d, 0xdf, 0x9b, 0x64, 
	0x9c, 0x89, 0xc0, 0x00, 0x00, 0x00, 0x00, 0x00, 0x00, 0x00, 0x3b, 0xf3, 0x6d, 0xdf, 0x9b, 0x64, 
	0xa2, 0x8a, 0x20, 0x00, 0x00, 0x00, 0x00, 0x00, 0x00, 0x00, 0x38, 0x13, 0x6d, 0xc0, 0x9b, 0x64, 
	0xa0, 0xf8, 0x20, 0x00, 0x00, 0x00, 0x00, 0x00, 0x00, 0x00, 0x3b, 0xf0, 0x91, 0xdf, 0x84, 0x84, 
	0xa0, 0x88, 0xc0, 0x00, 0x00, 0x00, 0x00, 0x00, 0x00, 0x00, 0x3b, 0xf0, 0x91, 0xdf, 0x84, 0x84, 
	0xa0, 0x89, 0x00, 0x00, 0x00, 0x00, 0x00, 0x00, 0x00, 0x00, 0x38, 0x00, 0x01, 0xc0, 0x00, 0x04, 
	0xa2, 0x8a, 0x00, 0x00, 0x00, 0x00, 0x00, 0x00, 0x00, 0x00, 0x38, 0x06, 0x01, 0xc0, 0xf8, 0x04, 
	0x9c, 0x8b, 0xe0, 0x00, 0x00, 0x00, 0x00, 0x00, 0x00, 0x00, 0x38, 0x06, 0x01, 0xc0, 0xf8, 0x04, 
	0x80, 0x00, 0x00, 0x00, 0x00, 0x00, 0x00, 0x00, 0x00, 0x00, 0x38, 0x06, 0x01, 0xc0, 0x04, 0x04, 
	0x80, 0x00, 0x00, 0x00, 0x00, 0x00, 0x00, 0x00, 0x00, 0x00, 0x38, 0x06, 0x01, 0xc0, 0x04, 0x04, 
	0x9c, 0x88, 0xe0, 0x00, 0x00, 0x00, 0x00, 0x00, 0x00, 0x00, 0x38, 0x06, 0x01, 0xc0, 0x18, 0x04, 
	0xa2, 0x89, 0x10, 0x00, 0x00, 0x00, 0x00, 0x00, 0x00, 0x00, 0x38, 0x06, 0x01, 0xc0, 0x20, 0x04, 
	0xa0, 0xf8, 0x10, 0x00, 0x00, 0x00, 0x00, 0x00, 0x00, 0x00, 0x38, 0x06, 0x01, 0xc0, 0x20, 0x04, 
	0xa0, 0x88, 0x60, 0x00, 0x00, 0x00, 0x00, 0x00, 0x00, 0x00, 0x38, 0x06, 0x01, 0xc0, 0xc0, 0x04, 
	0xa0, 0x88, 0x10, 0x00, 0x00, 0x00, 0x00, 0x00, 0x00, 0x00, 0x38, 0x06, 0x01, 0xc0, 0xfc, 0x04, 
	0xa2, 0x89, 0x10, 0x00, 0x00, 0x00, 0x00, 0x00, 0x00, 0x00, 0x38, 0x06, 0x01, 0xc0, 0xfc, 0x04, 
	0x9c, 0x88, 0xe0, 0x00, 0x00, 0x00, 0x00, 0x00, 0x00, 0x00, 0x38, 0x00, 0x01, 0xc0, 0x00, 0x04, 
	0x80, 0x00, 0x00, 0x00, 0x00, 0x00, 0x00, 0x00, 0x00, 0x00, 0x3f, 0xff, 0xff, 0xff, 0xff, 0xfc, 
	0x80, 0x00, 0x00, 0x00, 0x00, 0x00, 0x00, 0x00, 0x00, 0x00, 0x3f, 0xff, 0xff, 0xff, 0xff, 0xfc, 
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
};

const unsigned char DIGI_CLICKED [] PROGMEM = {
	0xff, 0xc0, 0xff, 0xc0, 0xff, 0xc0, 0xff, 0xc0, 0xff, 0xc0, 0xff, 0xc0, 0xff, 0xc0, 0xff, 0xc0, 
	0xff, 0xc0, 0xff, 0xc0
};

unsigned long previousCurrentTime = 0,previousTime = 0;

const uint64_t address = 0XE8E8F0F0E1LL;

RF24 radio(CE,CSN);

struct CHANNEL_DATA{
  byte throttle;
  byte yaw;
  byte roll;
  byte pitch;
  byte pot1;
  byte pot2;
  byte sw1;
  byte sw2;
};

CHANNEL_DATA data;

void send_data();
void display_data();

void setup() {
  // put your setup code here, to run once:
  pinMode(THROTTLE,INPUT);
  pinMode(YAW     ,INPUT);
  pinMode(ROLL    ,INPUT);
  pinMode(PITCH   ,INPUT);
  pinMode(POT1    ,INPUT);
  pinMode(POT2    ,INPUT);
  pinMode(SW1     ,INPUT);
  pinMode(SW2     ,INPUT);
  pinMode(TRCAL   ,INPUT);
  pinMode(YACAL   ,INPUT);
  pinMode(ROCAL   ,INPUT);
  pinMode(PICAL   ,INPUT);

  Wire.begin();
  Serial.begin(115200);
  if (!radio.begin()) {
    Serial.println(F("radio hardware is not responding!!"));
    while (1) {}  // hold in infinite loop
  }
  radio.setDataRate(RF24_250KBPS);
  radio.setAutoAck(false);                    // Ensure autoACK is enabled

  radio.setPALevel(RF24_PA_MIN);
  radio.openWritingPipe(address);
  radio.stopListening();

  calibrate();

  data.throttle = 127;
  data.yaw      = 127;
  data.roll     = 127;
  data.pitch    = 127;
  data.pot1     = 127;
  data.pot2     = 127;
  data.sw1      = 0;
  data.sw2      = 0;
  
  // SSD1306_SWITCHCAPVCC = generate display voltage from 3.3V internally
  display.setRotation(2);

  if(!display.begin(SSD1306_SWITCHCAPVCC, SCREEN_ADDRESS)) {
    Serial.println(F("SSD1306 allocation failed"));
    for(;;); // Don't proceed, loop forever
  }
  display.clearDisplay();
  delay(100); 
  display.clearDisplay();
  display.drawBitmap(0,0,WELCOME_SCREEN,128,64,SSD1306_WHITE);
  display.display();
  delay(500); 
  display.clearDisplay();
}

void loop() {
  send_data();
  display_data();  
  delayMicroseconds(100);
}

void calibrate(){
  long t = 0, y = 0, r = 0, p = 0;

  for(int i=0;i<100;i++){
    y += map(analogRead(YAW),1023,14,0,255);
    r += map(analogRead(ROLL),0,1023,0,255);
    p += map(analogRead(PITCH),0,1023,0,255);
    t += map(analogRead(THROTTLE),1023,0,0,255);
    delay(5);
  }

  THROTTLE_CENTER = t / 100;
  YAW_CENTER = y/100;
  PITCH_CENTER = p / 100;
  ROLL_CENTER = r / 100;
  



}
int applyDeadband(int value, int center, int deadband = 5){
   value += (127 - center);

  if(abs(value-127) <= deadband){
    return 127;
  }

  return constrain(value,0,255);
}

void send_data()
{
  data.throttle = map(analogRead(THROTTLE),1023,0,0,255);
  data.yaw      = applyDeadband(map(analogRead(YAW)     ,1023,14,0,255),YAW_CENTER,5);
  data.roll     = applyDeadband(map(analogRead(ROLL)    ,0,1023,0,255),ROLL_CENTER,5);
  data.pitch    = applyDeadband(map(analogRead(PITCH)   ,0,1023,0,255),PITCH_CENTER,5);
  data.pot1     = map(analogRead(POT1)    ,0,1023,0,255);  
  data.pot2     = map(analogRead(POT2)    ,0,1023,0,255);
  data.sw1      = digitalRead(SW1);
  data.sw2      = digitalRead(SW2);
  radio.write(&data,sizeof(CHANNEL_DATA));
 // Serial.println("SENT DATA");
}



void display_data()
{
    display.clearDisplay();
    display.drawBitmap(0,0,HOME,128,64,SSD1306_WHITE);

  
	if(data.sw1 == LOW)
      {
	display.drawBitmap( 92, 45,DIGI_CLICKED, 10,10,SSD1306_WHITE );   
      }
			
     if(data.sw2 == LOW)
      {
	display.drawBitmap( 110,45,DIGI_CLICKED, 10, 10, SSD1306_WHITE);
      }
			
      display.setTextSize(1); // Draw 2X-scale text
      display.setTextColor(SSD1306_WHITE);
      display.setCursor(24,4);
      display.print(data.throttle); 
      display.setCursor(24,13);
      display.print(data.yaw);
      display.setCursor(24,22);
      display.print(data.roll);
      display.setCursor(24,31);
      display.print(data.pitch);
      display.setCursor(24,40);
      display.print(data.pot1);
      display.setCursor(24,49);
      display.print(data.pot2);
      display.display();  
}

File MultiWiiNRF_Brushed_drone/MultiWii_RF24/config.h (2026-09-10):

#ifndef CONFIG_H_
#define CONFIG_H_

/*************************************************************************************************/
/****           CONFIGURABLE PARAMETERS                                                       ****/
/*************************************************************************************************/

/* this file consists of several sections
 * to create a working combination you must at least make your choices in section 1.
 * 1 - BASIC SETUP - you must select an option in every block.
 *      this assumes you have 4 channels connected to your board with standard ESCs and servos.
 * 2 - COPTER TYPE SPECIFIC OPTIONS - you likely want to check for options for your copter type
 * 3 - RC SYSTEM SETUP
 * 4 - ALTERNATE CPUs & BOARDS - if you have
 * 5 - ALTERNATE SETUP - select alternate RX (SBUS, PPM, etc.), alternate ESC-range, etc. here
 * 6 - OPTIONAL FEATURES - enable nice to have features here (FlightModes, LCD, telemetry, battery monitor etc.)
 * 7 - TUNING & DEVELOPER - if you know what you are doing; you have been warned
 *     - (ESCs calibration, Dynamic Motor/Prop Balancing, Diagnostics,Memory savings.....)
 * 8 - DEPRECATED - these features will be removed in some future release
 */

/* Notes:
 * 1. parameters marked with (*) in the comment are stored in eeprom and can be changed via serial monitor or LCD.
 * 2. parameters marked with (**) in the comment are stored in eeprom and can be changed via the GUI
 */


/*************************************************************************************************/
/*****************                                                                 ***************/
/****************  SECTION  1 - BASIC SETUP                                                *******/
/*****************                                                                 ***************/
/*************************************************************************************************/

  /**************************    The type of multicopter    ****************************/
    //#define GIMBAL
    //#define BI
    //#define TRI
    //#define QUADP
    #define QUADX
    //#define Y4
    //#define Y6
    //#define HEX6
    //#define HEX6X
    //#define HEX6H  // New Model
    //#define OCTOX8
    //#define OCTOFLATP
    //#define OCTOFLATX
    //#define FLYING_WING
    //#define VTAIL4
    //#define AIRPLANE
    //#define SINGLECOPTER
    //#define DUALCOPTER
    //#define HELI_120_CCPM
    //#define HELI_90_DEG

  /****************************    Motor minthrottle    *******************************/
    /* Set the minimum throttle command sent to the ESC (Electronic Speed Controller)
       This is the minimum value that allow motors to run at a idle speed  */
    //#define MINTHROTTLE 1300 // for Turnigy Plush ESCs 10A
    //#define MINTHROTTLE 1120 // for Super Simple ESCs 10A
    //#define MINTHROTTLE 1064 // special ESC (simonk)
    //#define MINTHROTTLE 1050 // for brushed ESCs like ladybird
    #define MINTHROTTLE 1000 // (*) (**)

  /****************************    Motor maxthrottle    *******************************/
    /* this is the maximum value for the ESCs at full power, this value can be increased up to 2000 */
    #define MAXTHROTTLE 2000

  /****************************    Mincommand          *******************************/
    /* this is the value for the ESCs when they are not armed
       in some cases, this value must be lowered down to 900 for some specific ESCs, otherwise they failed to initiate */
    #define MINCOMMAND  1000

  /**********************************  I2C speed for old WMP config (useless config for other sensors)  *************/
    #define I2C_SPEED 100000L     //100kHz normal mode, this value must be used for a genuine WMP
    //#define I2C_SPEED 400000L   //400kHz fast mode, it works only with some WMP clones

  /***************************    Internal i2c Pullups   ********************************/
    /* enable internal I2C pull ups (in most cases it is better to use external pullups) */
    //#define INTERNAL_I2C_PULLUPS

  /**********************************  constant loop time  ******************************/
    #define LOOP_TIME 2800

  /**************************************************************************************/
  /*****************          boards and sensor definitions            ******************/
  /**************************************************************************************/
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
